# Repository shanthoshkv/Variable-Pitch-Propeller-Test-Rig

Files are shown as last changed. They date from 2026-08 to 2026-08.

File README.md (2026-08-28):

# Variable Pitch Propeller Test Rig

Design, CFD analysis, 3D-printed prototype, and experimental thrust testing of a manually adjustable variable-pitch propeller.

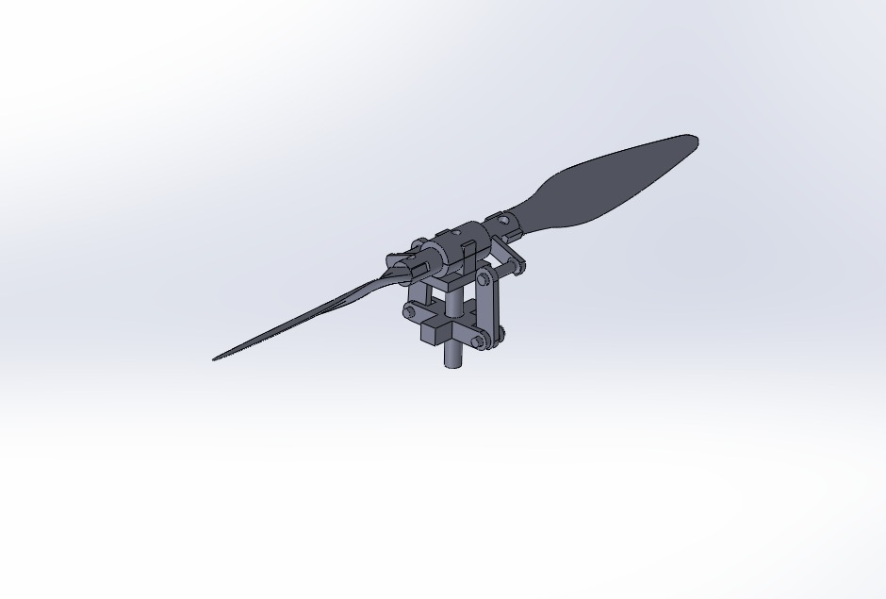
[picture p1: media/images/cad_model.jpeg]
CAD model of the variable-pitch propeller hub and blades


## Overview

Fixed-pitch propellers are only efficient at one operating point, the blade angle of attack that was optimal at the design condition goes off-optimal (or stalls) everywhere else. This project builds a variable-pitch propeller where blade pitch can be set mechanically via a rack-and-pinion hub, and tests how thrust changes with pitch angle from 0 to 30 degrees, using both CFD and a physical test bench, to see how closely a 3D-printed, non-actuated prototype tracks simulation.

Work was done as a group project (5 students, Aerospace Propulsion course, RVCE) covering the full pipeline: aerodynamic theory, CAD, CFD validation, fabrication, and instrumented testing.

## How it works

### Aerodynamic theory

The geometric pitch $P$ at blade radius $r$ relates to pitch angle $\beta$ by:

$$P = 2\pi r \tan(\beta)$$

and the propeller's operating condition is characterized by the advance ratio:

$$J = \frac{V}{nD}$$

where $V$ is advance velocity, $n$ is rotational speed (rev/s), and $D$ is diameter. Since this rig is a static-thrust bench (no forward airspeed), $J = 0$ for every test point, so the results characterize static thrust and stall onset vs. pitch, not the full thrust/efficiency curve across advance ratio.

Blade twist distribution was chosen so effective angle of attack stays reasonable across the pitch range rather than being optimized for one setting, following the approximation:

$$\theta(r) = \theta_{root} - \arctan\left(\frac{2(r - r_{hub})}{\pi r}\right)$$

where $\theta_{root}$ is root pitch angle and $r_{hub}$ is hub radius. This is the standard load-distribution twist used to keep the blade close to its aerodynamic optimum away from the hub region.

### Design and CFD

Blade geometry (twist distribution, chord, radius) was generated using Blade Element Momentum Theory (BEMT) via OpenProp, then parameterized in SolidWorks. Each of 16 pitch configurations (0 to 30 degrees) was simulated in SolidWorks Flow Simulation to get predicted thrust and to check for stall onset at low and high pitch extremes.

### Pitch mechanism

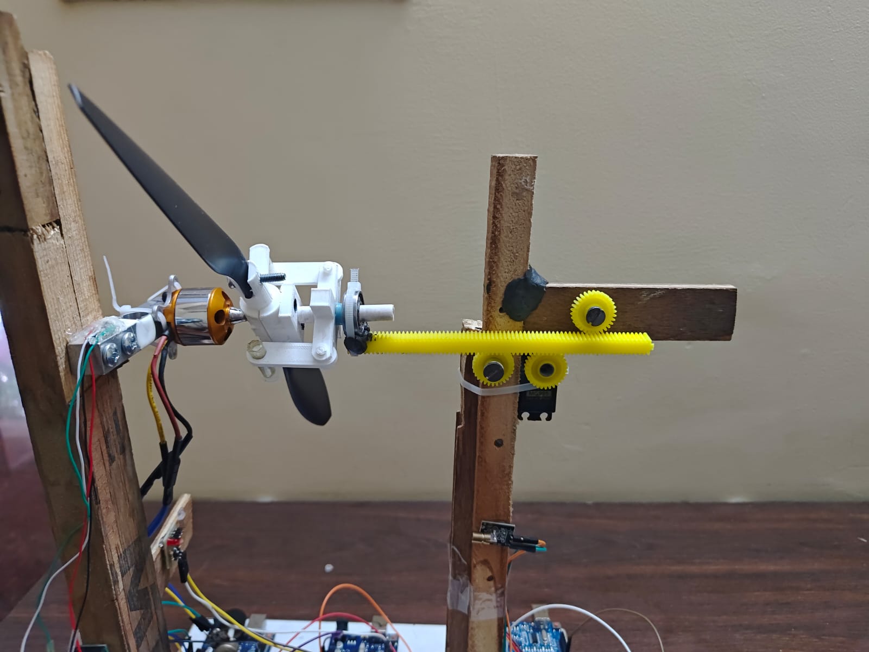
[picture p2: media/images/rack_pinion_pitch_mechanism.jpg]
Rack-and-pinion pitch mechanism, manually set and locked before each test run


A rack-and-pinion hub (`cad/hub.SLDPRT`, `cad/hub1.SLDPRT`, `cad/coupler.SLDPRT`) lets blade pitch be set manually and locked before a test run. It is not actuated in real time, there is no closed-loop pitch control here, this rig answers "how does thrust vary with pitch" rather than "can pitch be adjusted in flight."

### Fabrication

Blades and hub were 3D printed in PLA (`cad/print1 - CONT-1.STL`, `cad/print1 - string-1.STL`, and related STLs in `cad/`).

### Test bench

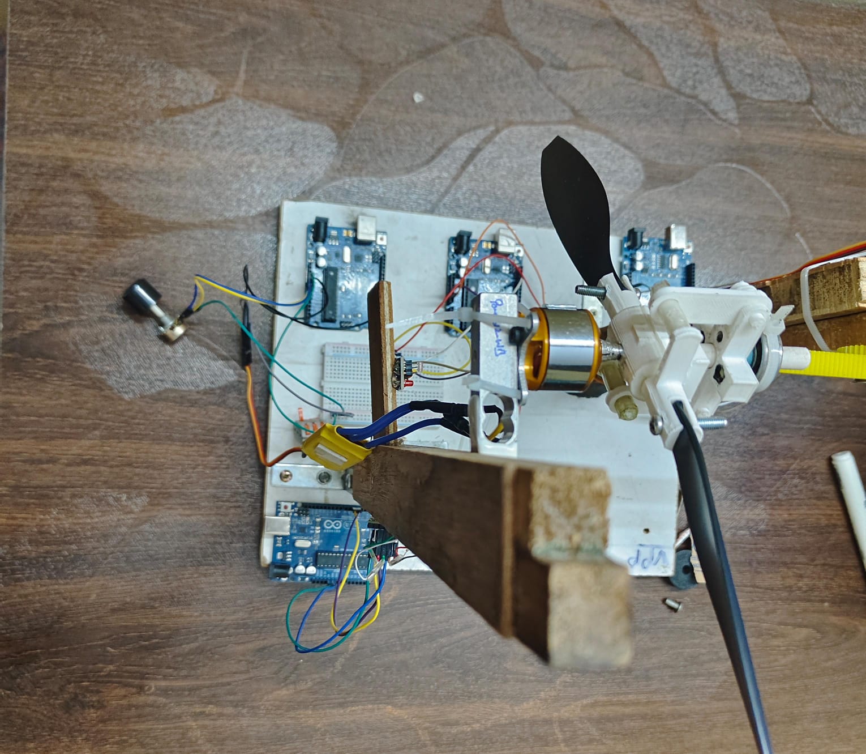
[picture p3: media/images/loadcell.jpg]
Test bench: brushless motor, load cell, and tachometer instrumentation


A brushless DC motor spins the prop. Three Arduino sketches handle instrumentation:

- `arduino-code/tachometer.ino` — RPM from an IR/optical blade-interrupt sensor, interrupt-driven with per-rotation smoothing.
- `arduino-code/loadcell.ino` / `loadcell_caliberation.ino` — thrust from an HX711 load cell amplifier, with a serial calibration routine (tare, known-mass calibration, EEPROM storage of the calibration factor) so the cell doesn't need re-calibrating on every boot.
- `arduino-code/rpm_control.ino` / `pitch_control_servo.ino` — motor speed and servo position set from a potentiometer for repeatable test-point setup.

For each pitch angle: lock the mechanism at that angle, spin up, and log RPM and thrust from the tachometer and load cell once readings settle.

## Results

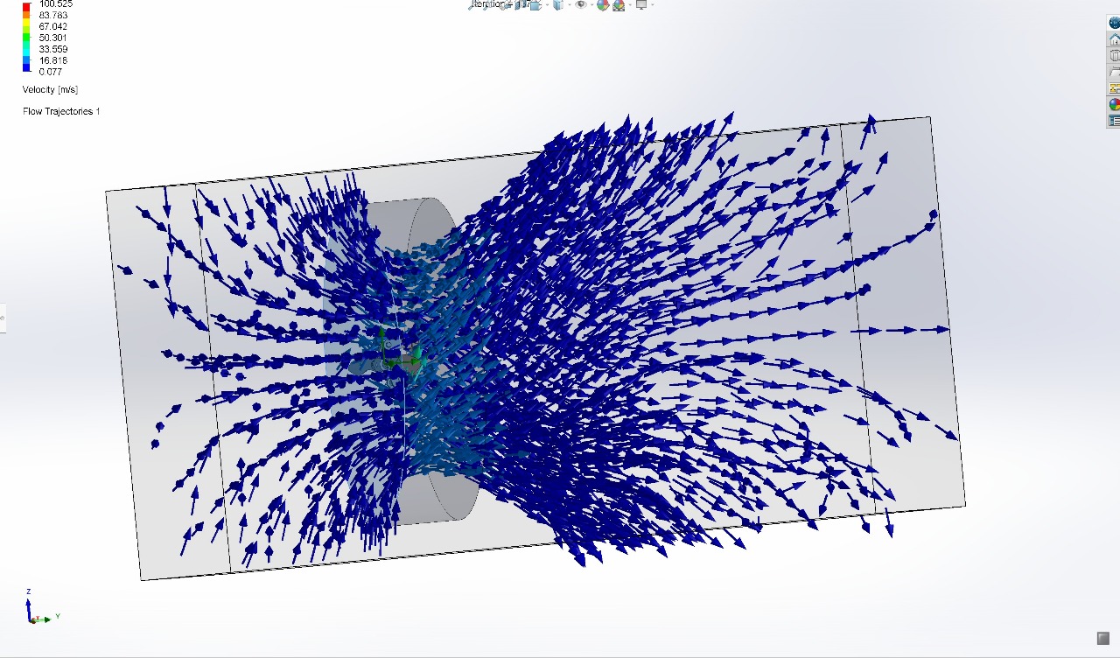
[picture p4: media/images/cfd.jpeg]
CFD flow simulation around the propeller at a test pitch angle


Max thrust of 3.00 N was observed at 28 degrees pitch, closely matching the CFD prediction. Thrust increases with pitch angle until aerodynamic stall effects start to reduce it near the top of the tested range. Experimental data tracked the simulated trend well across all 16 tested angles.

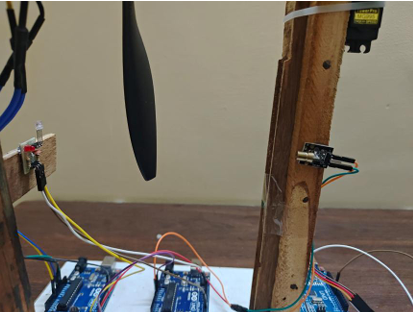
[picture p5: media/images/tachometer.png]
Tachometer readout during a test run


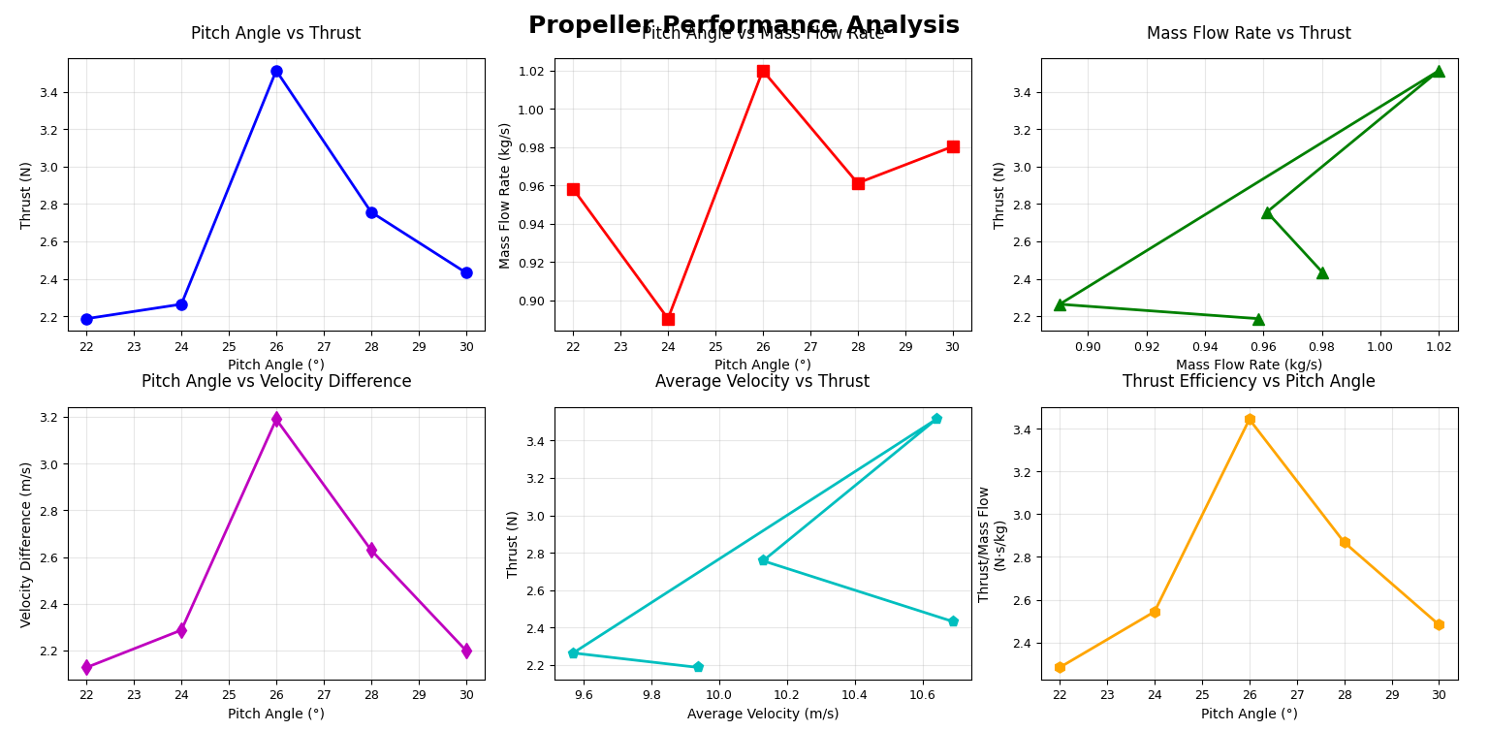
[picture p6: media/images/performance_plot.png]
Experimental and CFD thrust vs. pitch angle, showing the peak near 28 degrees


Video: `media/cad_pitch.mp4` (pitch mechanism CAD), `media/pitch_mechanism.mp4` (mechanism operation), `media/complete_working_model.mp4` (full test run).

Full writeup with methodology, CFD setup, theory background, and result plots: `docs/project_report.pdf`.

## Limitations

- Pitch is set manually between runs, not adjustable in flight or in real time, no closed-loop pitch actuator exists on this rig.
- Only 16 discrete pitch angles were tested, all at a single fixed RPM range from the bench motor, and all at $J = 0$ (static thrust only, no forward-flow/wind-tunnel testing).
- `media/images/python_output.png` implies a Python data-processing step was used to generate the result plots, but no Python script is checked into the repo, so the plotting step isn't reproducible from this repo alone.
- No structural/vibration analysis on the printed PLA blades at higher RPM, only the thrust and stall behavior were characterized.

## Repo layout

```
arduino-code/   RPM control, pitch servo control, tachometer, load cell + calibration
cad/            SolidWorks parts/assemblies and STLs for the hub, coupler, blades
docs/           full project report (PDF)
media/          photos, plots, and videos of the test rig and results
```

## Note

No matching page exists on the portfolio website for this project, this README is the primary documentation.

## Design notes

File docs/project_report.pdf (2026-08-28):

## RV COLLEGE OF ENGINEERING

## Design and Prototype Development of Variable Pitch Propeller

AEROSPACE PROPULSION

AS343AI

Under the Guidance of

Dr. Supreeth R

Associate Professor & Head Department of Aerospace Engineering

RV College of Engineering

In partial fulfilment for the award of degree of

Bachelor of Engineering

Aerospace Engineering

2024-2025

## RV COLLEGE OF ENGINEERING®, BENGALURU-59

Autonomous Institution Affiliated to VTU, Belagavi

## DEPARTMENT OF AEROSPACE ENGINEERING

CERTIFICATE

Certified that the Project Based Lab component of Aerospace Propulsion AS343AI course ti-

tled | is carried out by A

Uday Kiran (1RV23AS004), Rutuj Dugad Manoj (1RV23AS014), Tejas L (1RV23AS061),

Shanthosh K V (1RV23AS053), Yashwanth R (1RV23AS064) who are Bonafide students of

R.V. College of Engineering, Bengaluru, in partial fulfillment of the award of degree of Bach-

elor of Engineering in Aerospace Engineering of Visvesvaraya Technological University,

Belagavi during the year 2024-2025. It is certified that all corrections/suggestions indicated

for the Internal Assessment have been incorporated into the project-based laboratory report de-

posited in the departmental library. The report has been approved as it satisfies the academic

requirements in respect of Aerospace Propulsion Lab prescribed by the institution for the said

degree.

Signature of Internal Guide

External Viva

Name of Examiners | Signature with Date

1.

2.

I

RV COLLEGE OF ENGINEERING®
, BENGALURU-59

(Autonomous Institution Affiliated to VTU, Belag Vy, Belagavi)

DEPARTMENT OF AEROSPACE ENGINEERING

DECLARATION

We, A Uday Kiran (1RV23AS004), Rutuj Dugad Manoj (1RV23AS014), Tejas L (1RV23AS061),

Shanthosh K V (1RV23AS053), Yashwanth R (1RV23AS064), students of Fourth semester

B.E., Department of Aerospace Engineering, R.V. College of Engineering, Bengaluru, hereby

declare that the Project Based Lab of Aerospace Propulsion AS343AI course titled

has been carried out by us and

submitted in partial fulfilment for the award of degree of Bachelor of Engineering in Aerospace

Engineering during the year 2024-25.

Further, we declare that the content of the report has not been submitted previously by anybody

for the award of any degree or diploma to any other university.

We also declare that any Intellectual Property Rights generated out of this project carried out at

RVCE will be the property of the institute and we will be one of the authors of the same.

Place: Bengaluru

Date: 03/07/2025

Name | Signature

Akula Uday Kiran (1RV23AS004) Rutuj Dugad Manoj (1RV23AS014) Shanthosh K V (1RV23AS053) Tejas L (1RV23AS061) Yashwanth R (1RV23AS064)

II

## Acknowledgement

Our sincere thanks to Dr. Supreeth R, Associate Professor and Head, Department of Aerospace

Engineering, and the course coordinator for the Course Aerospace Propulsion AS343AI for his

support and encouragement.

We express our sincere gratitude to our beloved Principal, Dr. K. N. Subramanya for the

support for our Project Based Lab.

We thank all the teaching staff and technical staff of Aerospace Engineering department, RVCE, for

their help.

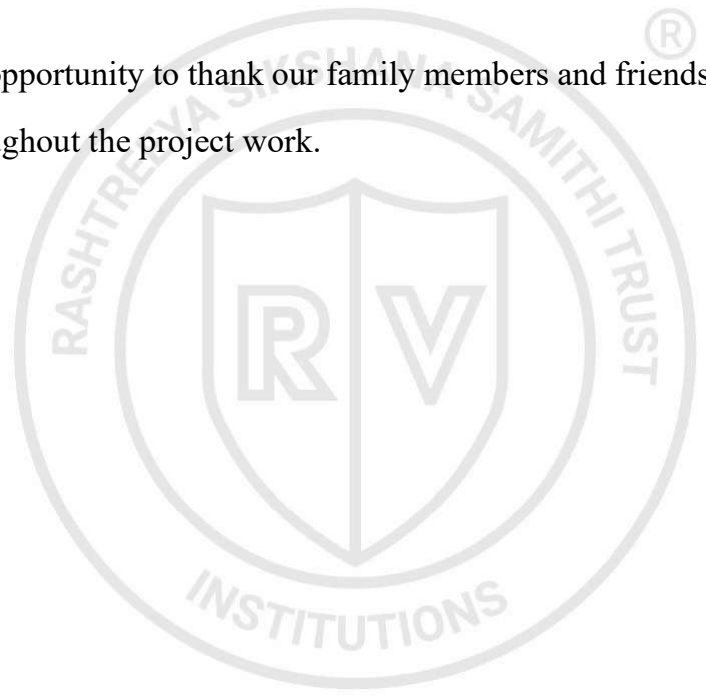
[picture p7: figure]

Lastly, we take this opportunity to thank our family members and friends who provided all the

backup support throughout the project work.

III

## Abstract

This project presents the design, simulation, fabrication, and experimental validation of a vari-

able pitch propeller system aimed at improving thrust generation across a range of operational

conditions. Unlike fixed-pitch systems, variable pitch propellers enable real-time adjustment

of blade pitch angles to optimize aerodynamic efficiency and propulsion performance. The

study begins with a detailed aerodynamic analysis using Blade Element and Momentum The-

ory, followed by parametric modeling in SolidWorks and simulation through CFD using Flow

Simulation tools. A total of 16 pitch configurations ranging from 0° to 30° were evaluated to

understand their influence on thrust.

The prototype was fabricated using 3D printing techniques in PLA material, and experimen-

tally tested using a brushless DC motor, load cell, and a tachometer-based thrust measurement

setup. Experimental data showed a strong correlation with simulation results, with the maxi-

mum thrust of 3.00 N observed at a pitch angle of 28°, closely matching simulated predictions.

The results confirmed that increased pitch angles lead to enhanced thrust until aerodynamic

stall effects appear. The study highlights the feasibility of manually tunable propeller blades

and lays the groundwork for future development of servo-actuated dynamic pitch systems for

UAVs and other aerospace platforms.

IV

# Contents

Certificate
Declaration
Acknowledgement
Abstract
1 Introduction | 1
2 CAD Modelling, CFD Analysis, Experimental model and Analysis | 5

V

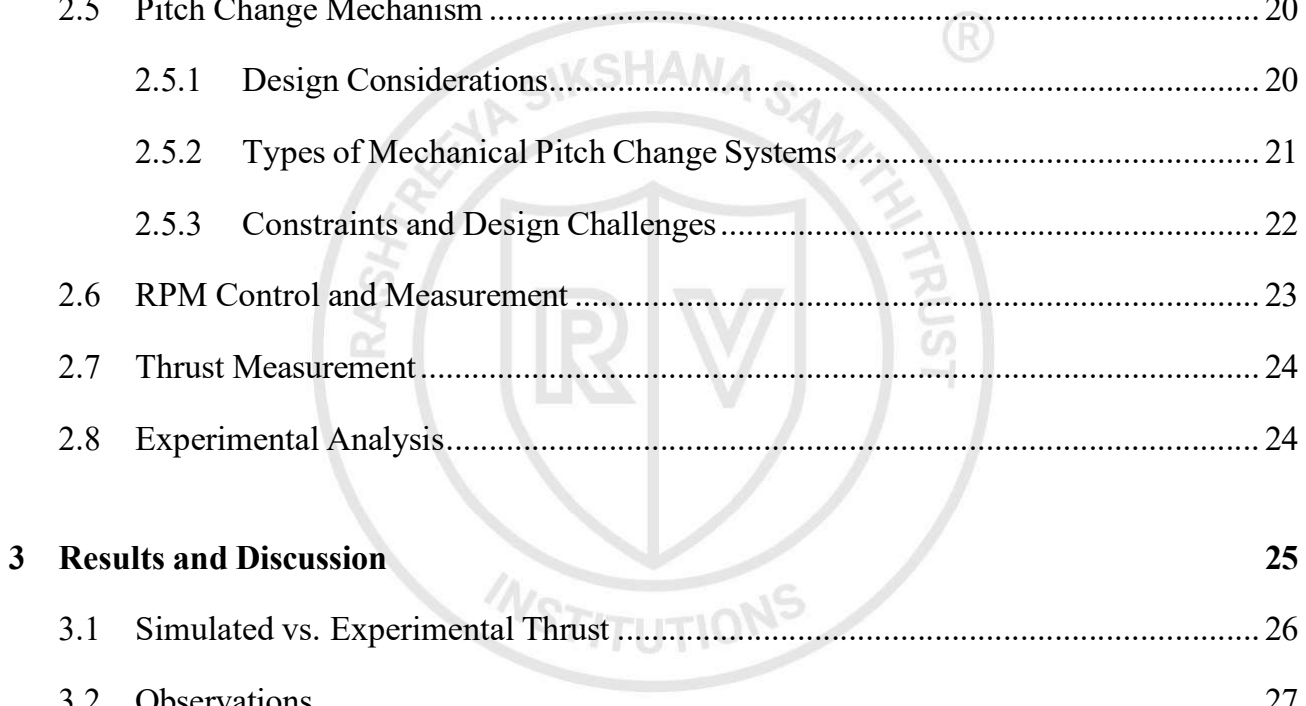
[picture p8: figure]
3 Results and Discussion

4 Conclusion and Future scope | 28

VII

# List of Figures

### 2.1 OpenProp Input Parameters | 17

### 2.2 Propeller Profiles | 17

### 2.3 Propeller Profiles in SolidWorks | 18

### 2.4 Bolt design and pitch controller | 18

### 2.5 Coupler design and hub design | 19

### 2.6 Final Assembly | 19

### 2.7 Flow simulation of propeller at a pitch angle of 20 degrees | 20

### 2.8 Goal plots extracted from simulation of propeller at a pitch angle of 20 degrees 20

### 2.9 Velocity contour of the propeller at a pitch angle of 20 degrees | 20

### 2.10 Flow simulation shows stalling at 2 degrees | 21

### 2.11 Flow simulation shows stalling at 30 degrees | 21

### 2.12 Pitch change mechanism | 29

### 2.13 Tachometer | 30

### 2.14 RPM Control and Thrust Measurement | 30

VIII

Variable Pitch Propeller

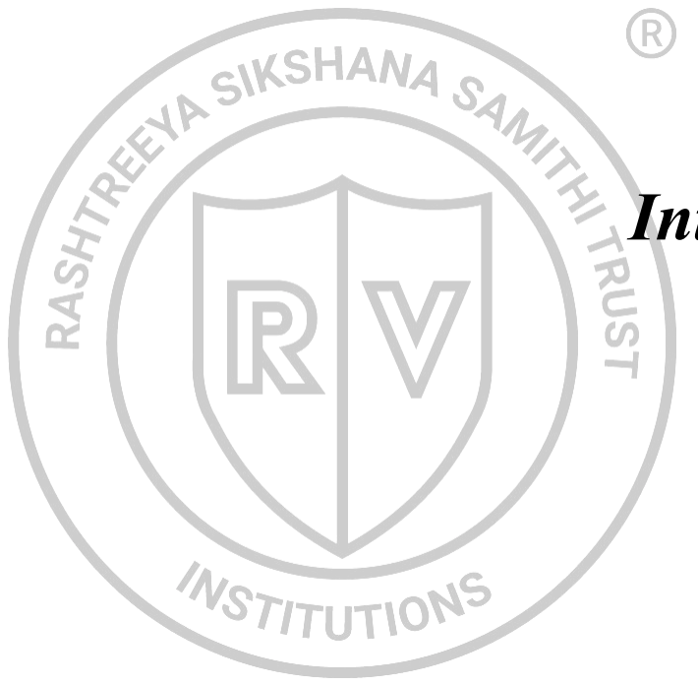
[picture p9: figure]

Department of Aerospace Engineering | 2024-2025 | Page 1

# Chapter 1 Introduction

Variable pitch propellers represent one of the most significant technological advancements in

propulsion systems, fundamentally transforming how aircraft and marine vessels optimize their

performance across varying operational conditions. Unlike fixed-pitch propellers that maintain

constant blade angles, variable pitch propellers enable real-time adjustment of blade pitch an-

gles, allowing for optimal thrust generation and efficiency across different flight phases or

operating speeds.

The concept of variable pitch propulsion emerged from the inherent limitations of fixed-pitch

systems, which can only achieve optimal efficiency at a single design point. In aviation, air-

craft experience dramatically different operating conditions during takeoff, climb, cruise, and

landing phases, each requiring different thrust and efficiency characteristics. Similarly, marine

vessels encounter varying sea conditions, speeds, and loading scenarios that benefit from pitch

adjustment capabilities.

The development of variable pitch propeller technology has been driven by the continuous pur-

suit of improved fuel efficiency, enhanced performance, and operational flexibility. Modern

variable pitch systems incorporate sophisticated control mechanisms, advanced materials, and

precise manufacturing techniques to achieve remarkable levels of performance optimization.

These systems have become standard equipment in commercial aviation, military aircraft, and

high-performance marine applications.

This report provides a comprehensive examination of variable pitch propeller technology, ex-

ploring the theoretical foundations, design principles, control systems, and practical applica-

tions that define modern propulsion systems. The analysis encompasses both aerospace and

marine applications, highlighting the unique challenges and solutions associated with each do-

main.

### 1.1 Propeller Aerodynamics and Hydrodynamics

The operation of variable pitch propellers is governed by fundamental principles of fluid dy-

namics, whether operating in air for aircraft or water for marine vessels. Understanding these

principles is essential for comprehending how pitch variation affects propeller performance and

overall system efficiency.

### 1.1.1 Pitch Angle Effects

The pitch angle β fundamentally determines the propeller‘s thrust and torque characteristics.

Increasing pitch angle generally increases the theoretical advance per revolution but also in-

creases the angle of attack, potentially leading to stall conditions. The relationship between

pitch angle and performance is complex and depends on operating conditions.

The geometric pitch P at radius r is related to the pitch angle by:

P = 2πr tan(β) | (1.1)

The advance ratio J is a dimensionless parameter that characterizes the propeller‘s operating

condition:

(1.2)

where V is the advance velocity.

Variable pitch propellers employ various mechanical systems to adjust blade pitch angles during

operation. The choice of mechanism depends on application requirements, including response

time, precision, reliability, and power consumption.

### 1.2.1 Hydraulic Systems

Hydraulic pitch control systems are widely used in aviation applications due to their high

power-to-weight ratio and rapid response capabilities. These systems typically employ engine

oil or dedicated hydraulic fluid to actuate pitch change mechanisms.

The basic hydraulic system consists of a governor unit that senses propeller speed and controls

oil flow to a pitch change mechanism within the propeller hub. The pitch change mechanism

converts hydraulic pressure into mechanical motion that rotates the propeller blades about their

longitudinal axes.

### 1.2.2 Electric Systems

Electric pitch control systems offer precise control and are increasingly used in modern appli-

cations. These systems employ electric motors, typically stepper motors or servo motors, to

drive pitch change mechanisms through gear reduction systems.

The torque requirements for electric pitch control systems must overcome both aerodynamic

moments and system friction:

Tmotor = Taero + Tfriction + Jsystemαangular | (1.3)

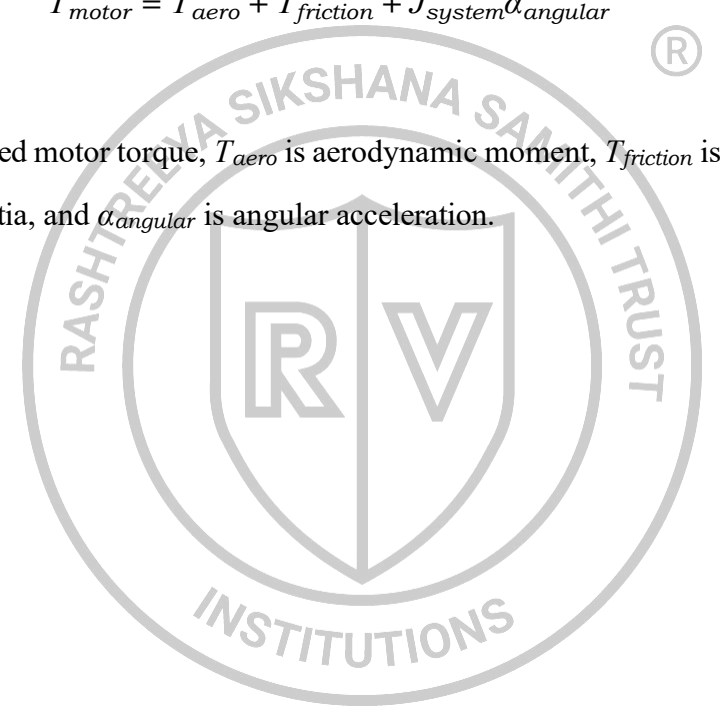
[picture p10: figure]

where Tmotor is required motor torque, Taero is aerodynamic moment, Tfriction is friction torque,

Jsystem is system inertia, and αangular is angular acceleration.

# Chapter 2

π
r

### 2.1 Blade Design and Geometry

The design of variable pitch propeller blades requires careful consideration of aerodynamic ef-

ficiency, structural integrity, and manufacturing constraints. Unlike fixed-pitch blades, variable

pitch blades must maintain acceptable performance across a wide range of pitch angles.

### 2.1.1 Twist Distribution

Blade twist distribution must be optimized for variable pitch operation, considering that the

effective twist changes as pitch angle varies. The total twist at any radial station is the sum of

built-in geometric twist and pitch angle adjustment.

The optimal twist distribution for maximum efficiency can be approximated by:

β(r) = β −

2
arctan

(
rhub

)
(2.1)

where βroot is root pitch angle and rhub is hub radius.

### 2.1.2 Geometric Parameters

Number of Blades: The number of propeller blades affects thrust distribution, vibration char-

acteristics, and manufacturing complexity. Fewer blades generally provide higher efficiency but

may result in increased vibration and noise. More blades offer smoother operation and better

thrust distribution but at the cost of increased complexity and potential efficiency penalties.

Rotor Diameter: The propeller diameter is one of the most critical design parameters, directly

affecting the propeller‘s thrust-producing capability and efficiency. Larger diameters generally

provide better efficiency due to lower disk loading, but are constrained by ground clearance,

structural considerations, and installation requirements.

Hub Diameter: The hub diameter defines the central portion of the propeller and affects the

blade root design, structural attachment, and flow characteristics near the hub. The hub-to-tip

ratio influences the effective working area of the propeller and affects both performance and

root

structural design.

### 2.1.3 Operating Conditions

Rotation Speed (RPM): The propeller rotational speed determines the blade tip speed and af-

fects both aerodynamic performance and structural loads. Higher rotational speeds can provide

more thrust from a given diameter but may encounter compressibility effects and increased

noise at high tip speeds.

Ship Speed (Forward Velocity): This parameter defines the advance velocity of the propeller

through the fluid medium. It is crucial for determining the advance ratio, which characterizes

the propeller‘s operating condition and affects the angle of attack distribution along the blade.

Required Thrust: The design thrust requirement determines the propeller‘s loading and influ-

ences blade geometry optimization. This parameter is typically derived from the vehicle‘s drag

characteristics and performance requirements.

Fluid Density: The density of the operating medium (air or water) affects thrust production,

power requirements, and Reynolds number. This parameter varies with altitude, temperature,

and atmospheric conditions for aircraft, or with water temperature and salinity for marine ap-

plications.

### 2.1.4 Computational Grid Parameters

Radial Panels: This parameter defines the number of computational divisions along the blade

span from hub to tip. More radial panels provide higher resolution in the spanwise direction,

allowing for more accurate representation of blade geometry and flow characteristics. However,

increased panel count also increases computational time and complexity.

Chordwise Panels: This parameter specifies the number of computational divisions along the

blade chord from leading edge to trailing edge. Higher chordwise panel counts improve the

accuracy of pressure distribution calculations and airfoil representation, particularly important

for capturing leading edge and trailing edge effects.

### 2.1.5 Blade Geometry Parameters

r/R (Radial Position): This dimensionless parameter represents the radial position along the

blade span, where r is the local radius and R is the propeller tip radius. Values range from the

hub ratio (typically 0.15-0.25) to 1.0 at the tip. This parameter defines the stations where blade

properties are specified.

c/D (Chord-to-Diameter Ratio): This parameter defines the local blade chord length as a

fraction of the propeller diameter. The chord distribution affects blade loading, structural char-

acteristics, and manufacturing requirements. Optimal chord distributions balance aerodynamic

efficiency with structural and manufacturing constraints.

Cd (Drag Coefficient): The local drag coefficient represents the airfoil section ‘s drag charac-

teristics at each radial station. This parameter is typically derived from airfoil data and affects

the propeller ‘s power requirements and efficiency calculations.

t0/D (Thickness-to-Diameter Ratio): This parameter defines the maximum blade thickness at

each radial station as a fraction of the propeller diameter. Blade thickness distribution affects

structural strength, manufacturing requirements, and aerodynamic performance.

Skew: Blade skew refers to the circumferential offset of blade sections at different radial po-

sitions. Skew is used to reduce noise, vibration, and cavitation by distributing blade loading

more evenly in time. Forward skew moves outer blade sections ahead of inner sections in the

direction of rotation.

Xs/D (Skew Distribution): This parameter quantifies the skew distribution along the blade

span. The skew distribution affects the propeller ‘s acoustic signature, vibration characteristics,

and hydrodynamic performance.

### 2.1.6 Parametric Design using OpenProp

The design process begins with processing input parameters:

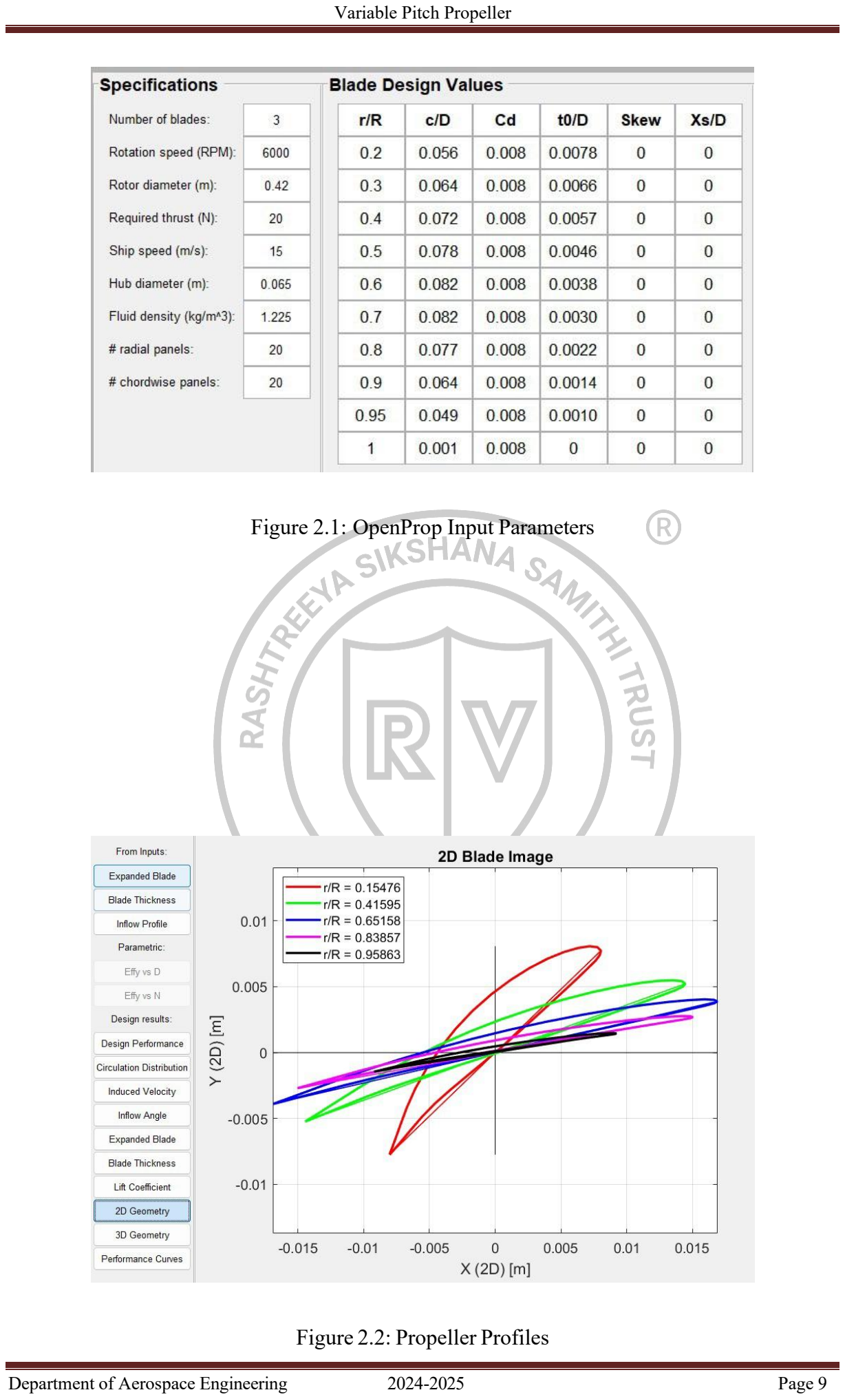
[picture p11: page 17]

Figure 2.1: OpenProp Input Parameters

Figure 2.2: Propeller Profiles

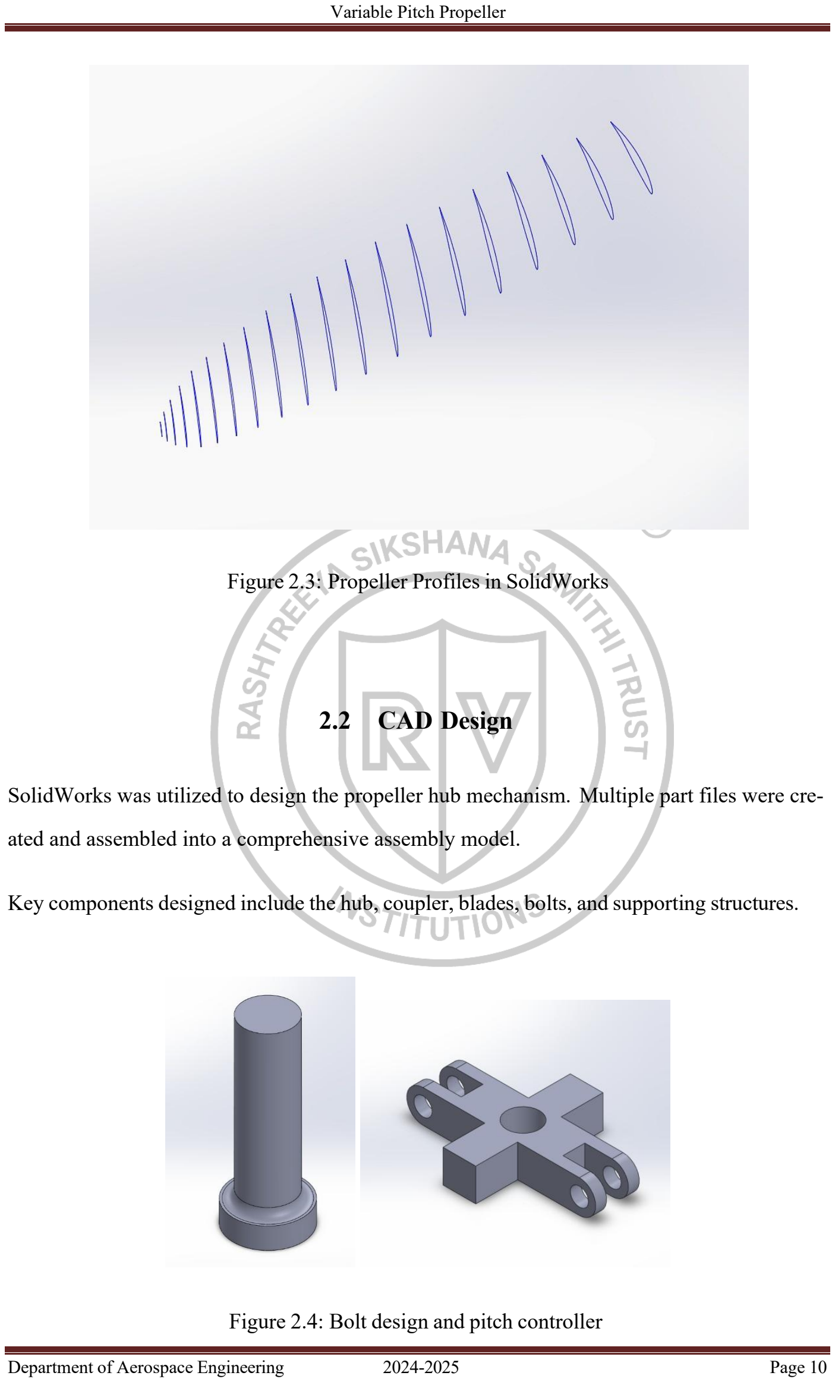
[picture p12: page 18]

Figure 2.3: Propeller Profiles in SolidWorks

### 2.2 CAD Design

SolidWorks was utilized to design the propeller hub mechanism. Multiple part files were cre-

ated and assembled into a comprehensive assembly model.

Key components designed include the hub, coupler, blades, bolts, and supporting structures.

Figure 2.4: Bolt design and pitch controller

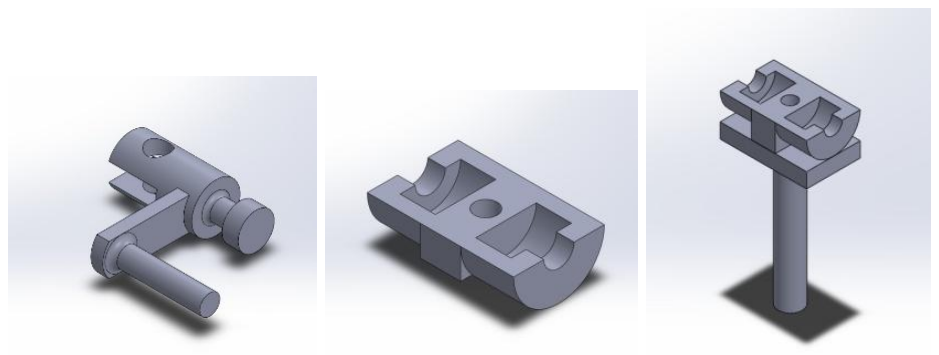
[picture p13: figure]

Figure 2.5: Coupler design and hub design

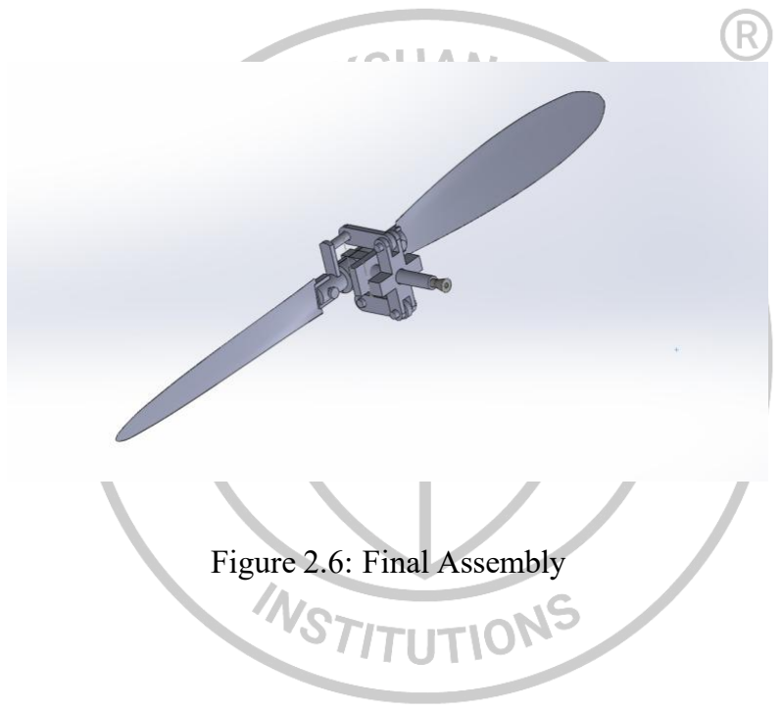
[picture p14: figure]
Figure 2.6: Final Assembly

### 2.3 CFD Simulations

For computational fluid dynamics (CFD) analysis, SolidWorks Flow Simulation was employed.

Appropriate boundary conditions were defined, including an environmental pressure setup. All

simulations were performed at an operating speed of 3000 RPM to evaluate aerodynamic per-

formance.

Below are the related simulation and model images:

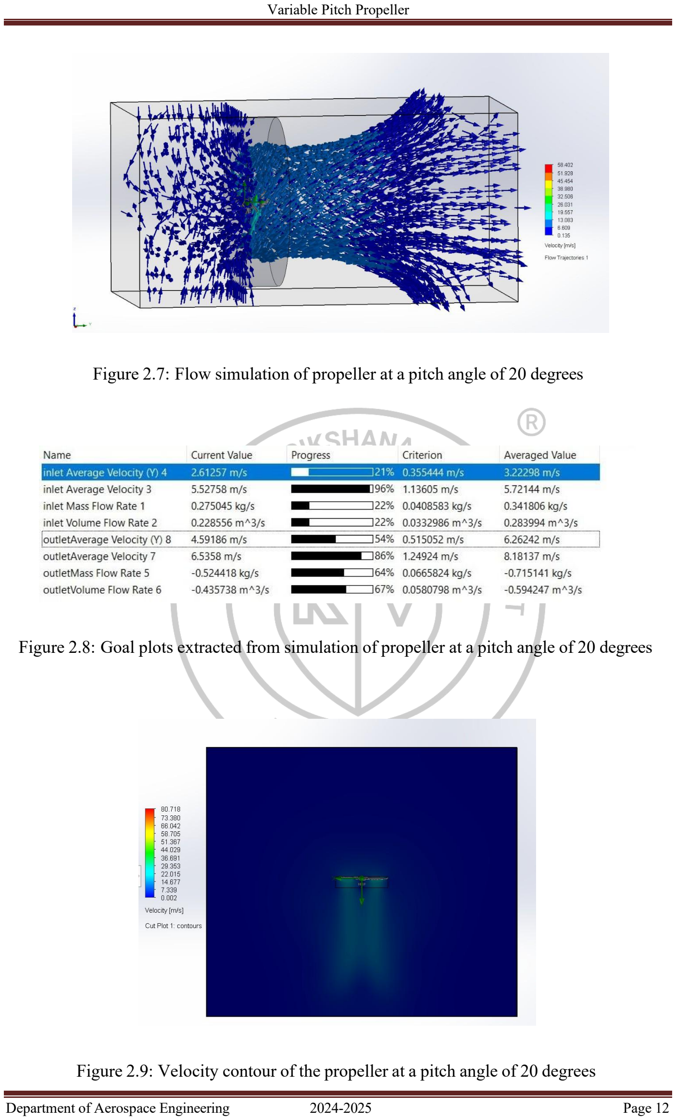
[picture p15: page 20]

Figure 2.7: Flow simulation of propeller at a pitch angle of 20 degrees

Figure 2.8: Goal plots extracted from simulation of propeller at a pitch angle of 20 degrees

Figure 2.9: Velocity contour of the propeller at a pitch angle of 20 degrees

### 2.3.1 Stall Analysis

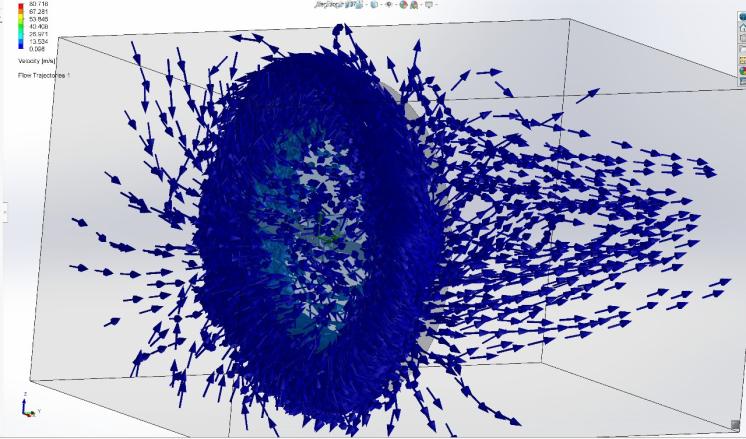
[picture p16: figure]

Figure 2.10: Flow simulation shows stalling at 2 degrees.

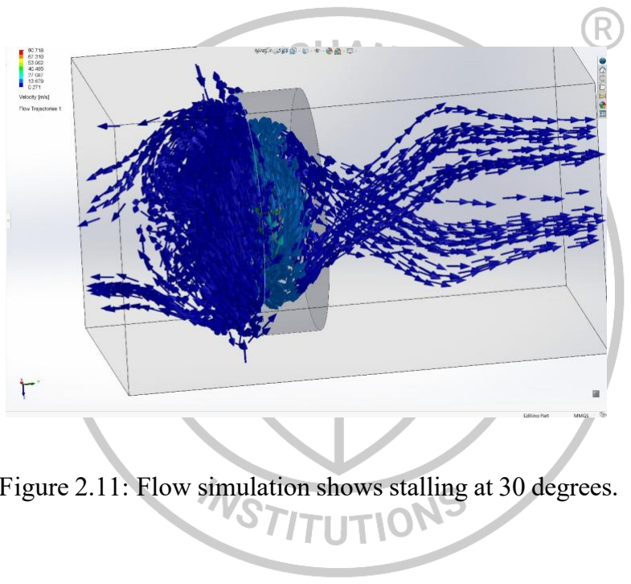
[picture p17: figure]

Figure 2.11: Flow simulation shows stalling at 30 degrees.

### 2.4 Methodology

The following methodology outlines the comprehensive steps taken to design, simulate, fabri-

cate, and test a variable pitch propeller system. This includes both computational simulations

in SolidWorks and CFD tools, as well as physical prototyping using 3D printing and real-world

thrust testing.

### 2.4.1 Project Workflow Overview

The methodology is divided into the following key stages:

- Conceptual Design and Pitch Mechanism Study
- CAD Modelling of Blades and Hub in SolidWorks
- Pitch Angle Variations and Configuration Generation
- CFD Simulation in Flow Simulation Module
- Physical Fabrication Using 3D Printing
- Experimental Setup Development
- Thrust Measurement and Data Collection

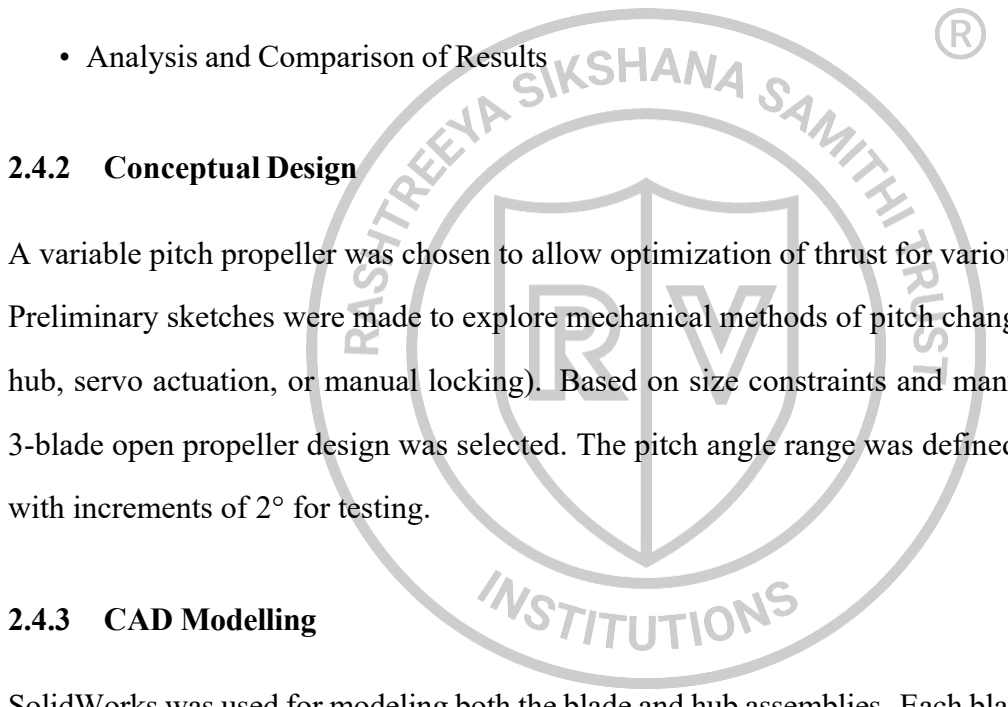
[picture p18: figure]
• Analysis and Comparison of Results; 2.4.2 Conceptual Design; with increments of 2° for testing.; 2.4.3 CAD Modelling

A variable pitch propeller was chosen to allow optimization of thrust for various flight phases.

Preliminary sketches were made to explore mechanical methods of pitch change (e.g., rotating

hub, servo actuation, or manual locking). Based on size constraints and manufacturability, a

3-blade open propeller design was selected. The pitch angle range was defined from 0° to 30°

SolidWorks was used for modeling both the blade and hub assemblies. Each blade was designed

with a root rotation feature, allowing pitch variation. Blades were parametrically modelled to

allow quick pitch adjustments using the design table. 16 configurations were generated for

pitch angles from 0° to 30° (0°, 2°, 4°, ..., 30°). The hub was designed with radial sockets to

hold the blade roots securely while allowing rotation.

### 2.4.4 CFD Simulation of Each Pitch Angle

The Flow Simulation module in SolidWorks was used to simulate airflow across the propeller

blades at each pitch. Boundary Conditions:

- Inlet velocity calculated based on rotational speed (3000 RPM).
- Environmental air, standard sea-level conditions.
- Rotation region was used to simulate the propeller motion.

Simulations were run for each pitch angle to extract:

- Thrust force
- Drag force
- Lift-to-drag ratio

Post-processing involved comparing force output vs pitch angle and identifying optimal per-

formance range.

### 2.4.5 Fabrication

3D printing (FDM type, PLA material) was used for blade and hub production. Each blade was

printed with locking holes for setting pitch manually using alignment pins. The hub was printed

as a modular design to enable easy insertion and removal of blades. Blades were sanded,

balanced, and checked for alignment before mounting.

### 2.4.6 Test Bench and Experimental Setup

The physical setup involved:

- DC brushless motor (3000 RPM rated) as the propulsion source.
- Laser tachometer to measure actual RPM.
- Load cell-based thrust measurement system mounted behind the propeller.
- A digital pitch protractor to verify pitch angle before testing.
- Control system to adjust RPM via ESC and throttle input.

### 2.4.7 Experimental Procedure

- Blade pitch was set manually using alignment pins at predefined angles.
- Motor RPM was increased incrementally using a throttle controller.
- For each pitch angle, thrust data was recorded at 3000 RPM.
- Five trials were taken for each configuration to average out fluctuations.
- The final measured thrust values were compared against simulation results.

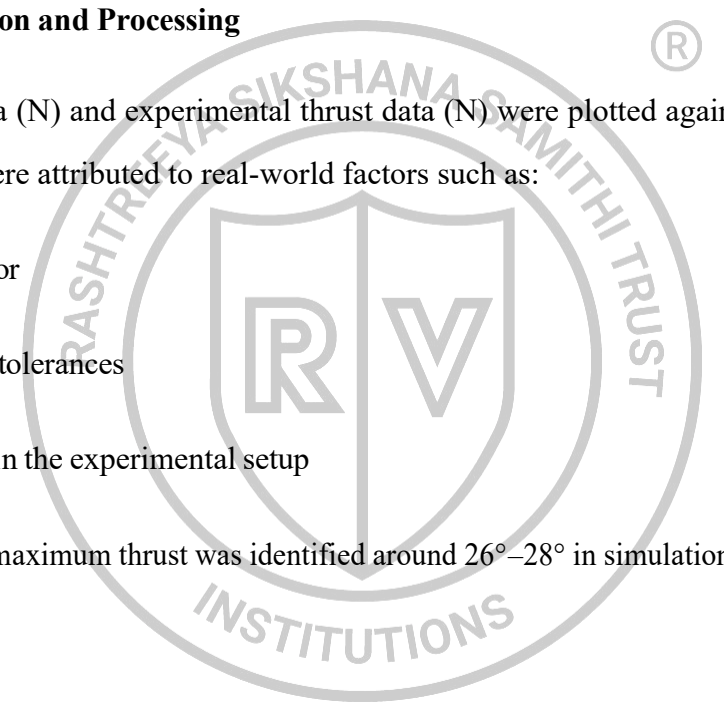
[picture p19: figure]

### 2.4.8 Data Collection and Processing

Simulation thrust data (N) and experimental thrust data (N) were plotted against pitch angles.

Any discrepancies were attributed to real-world factors such as:

- Tachometer error
- Manufacturing tolerances
- Airflow losses in the experimental setup

The optimal pitch for maximum thrust was identified around 26°–28° in simulation and 24°–26° in

physical tests.

### 2.4.9 RPM Control System

To rotate the propeller at the required speed for testing, a brushless DC (BLDC) motor was

used. It was controlled using an Electronic Speed Controller (ESC) interfaced with a throttle

system.

- Motor: A high-torque BLDC motor rated for continuous operation at 3000 RPM.
- ESC: An electronic controller capable of translating PWM (pulse-width modulation)

signals from the throttle to the motor.

- Power Source: A stable 12V–14.8V DC power supply or LiPo battery.
- Throttle Input: Manual potentiometer-based throttle to precisely vary the motor speed.

The ESC allowed for smooth acceleration and fine RPM adjustment to match the simulation

condition of 3000 RPM.

This section outlines the experimental procedures, instruments, and findings associated with

measuring thrust and controlling propeller performance in the physical prototype. It comple-

ments the simulation studies by validating them through practical data.

### 2.4.10 RPM Control and Measurement

RPM Control System

To rotate the propeller at the required speed for testing, a brushless DC (BLDC) motor was

used. It was controlled using an Electronic Speed Controller (ESC) interfaced with a throttle

system.

- Motor: A high-torque BLDC motor rated for continuous operation at 3000 RPM.
- ESC: An electronic controller capable of translating PWM (pulse-width modulation)

signals from the throttle to the motor.

- Power Source: A stable 12V–14.8V DC power supply or LiPo battery.
- Throttle Input: Manual potentiometer-based throttle to precisely vary the motor speed.

The ESC allowed for smooth acceleration and fine RPM adjustment to match the simulation

condition of 3000 RPM.

RPM Measurement

To accurately measure the RPM of the rotating propeller, a non-contact laser tachometer was

used. Working Principle: A small piece of reflective tape was applied to the hub of the ro-

tating propeller. The tachometer emitted a laser beam and detected the tape’s reflection during each revolution. Device Used: Handheld digital laser tachometer (±10 RPM accuracy). Lim-

itations: While effective, there is potential for measurement delay or under-reading at high

speeds due to light interference or misalignment. Note: In testing, the tachometer sometimes

read ∼2800–2950 RPM, though the motor was calibrated for 3000 RPM. This small discrep-

ancy may explain why experimental thrust exceeded simulation predictions.

### 2.4.11 Thrust Measurement

Purpose

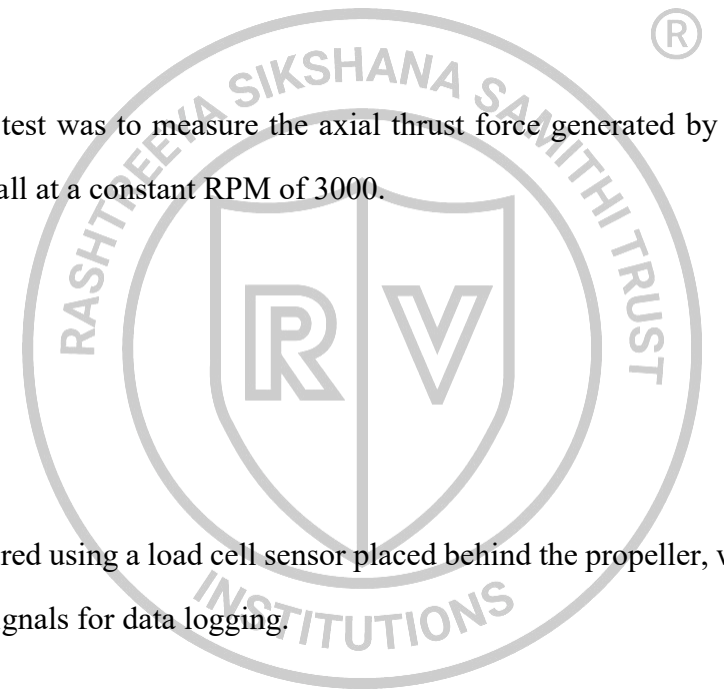
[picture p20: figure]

The core goal of the test was to measure the axial thrust force generated by the propeller at

various pitch angles, all at a constant RPM of 3000.

Setup Description

The thrust was measured using a load cell sensor placed behind the propeller, which converted

force into electrical signals for data logging.

Table 2.1: Equipment Used in Thrust Measurement

Component | Description
Load Cell HX711 Amplifier Arduino UNO Test Stand Propeller Mount | 5 kg strain gauge, linear output Signal amplifier and ADC module for load cell Microcontroller for data logging Rigid frame to isolate vibration and torque Center-aligned shaft for consistent rotation

### 2.4.12 Experimental Results and Analysis

Summary of Results

Table 2.2: Simulated vs Experimental Thrust

Pitch Angle (°) | Avg Simulated Thrust (N) | Avg Experimental Thrust (N)
0 2 4 . 24 26 28 30 | 0.12 0.26 0.39 . 2.10 2.18 2.20 2.19 | 0.16 0.29 0.41 . 2.81 2.90 3.00 2.97

Observations

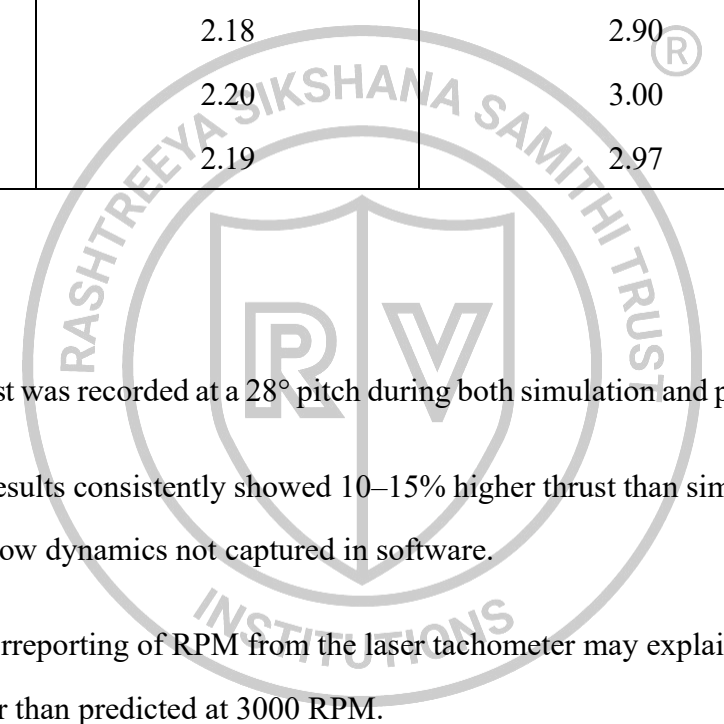
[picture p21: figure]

- Maximum thrust was recorded at a 28° pitch during both simulation and physical testing.
- Experimental results consistently showed 10–15% higher thrust than simulations, likely

due to real airflow dynamics not captured in software.

- The slight underreporting of RPM from the laser tachometer may explain why thrust

appeared higher than predicted at 3000 RPM.

Sources of Error

Table 2.3: Identified Sources of Error

Source | Explanation
Tachometer Delay/Error Airflow Recirculation Load Cell Drift 3D Print Tolerances | RPM may be lower than actual, leading to thrust mismatch. Indoor testing caused unsteady flow near the wall. Minor thermal or electrical drift during operation. Surface roughness may increase lift in some conditions.

Improvements for Future Testing

- Use a high-speed camera with motion tracking for RPM validation.
- Mount propeller in an open wind tunnel to minimize airflow recirculation.
- Introduce automated pitch control using servos for dynamic pitch testing.

### 2.4.13 Improvements for Future Testing

- Use a high-speed camera with motion tracking for RPM validation.

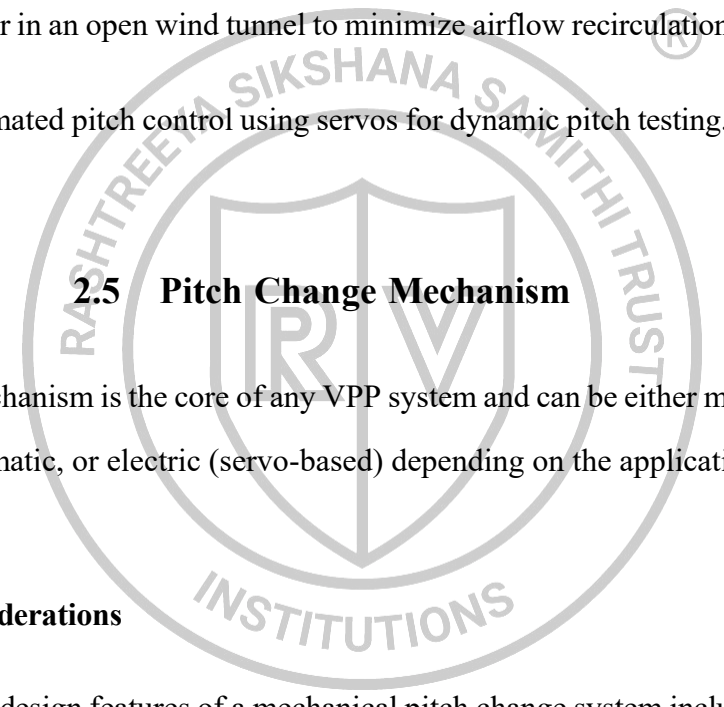
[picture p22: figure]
2.5 Pitch Change Mechanism

- Mount propeller in an open wind tunnel to minimize airflow recirculation.
- Introduce automated pitch control using servos for dynamic pitch testing.

The pitch change mechanism is the core of any VPP system and can be either manual, mechan-

ical, hydraulic, pneumatic, or electric (servo-based) depending on the application scale.

### 2.5.1 Design Considerations

Key components and design features of a mechanical pitch change system include:

a. Blade Root Bearings

Each blade is mounted in the hub using a bearing arrangement that permits it to rotate smoothly

about its axis. Common bearing types include:

- Radial ball bearings
- Thrust bearings for axial loads b. Rotating Sleeve / Hub Socket

The hub houses a rotating sleeve or cam mechanism that either directly rotates the blade roots

or transmits rotation from an actuation source (like a servo arm).

c. Pushrod or Rack Mechanism

A pushrod or gear rack system can be used to transmit axial motion to the rotating part of the

blade. For example:

- A conical cam pushes against a slot in the blade root

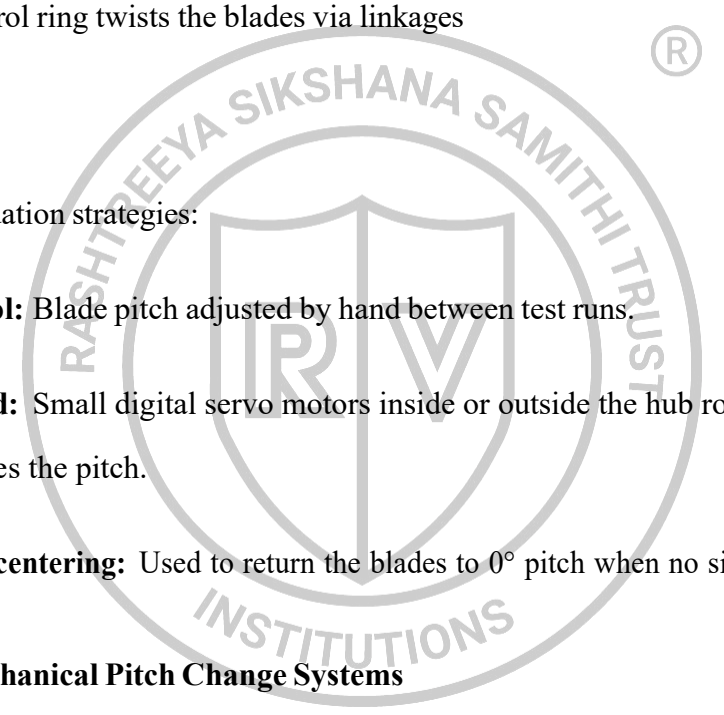
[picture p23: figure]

- A rotating control ring twists the blades via linkages
d. Actuation System

There are several actuation strategies:

- Manual control: Blade pitch adjusted by hand between test runs.
- Servo-actuated: Small digital servo motors inside or outside the hub rotate a control

ring that changes the pitch.

- Spring-loaded centering: Used to return the blades to 0° pitch when no signal is applied.

### 2.5.2 Types of Mechanical Pitch Change Systems

Rotating Collar Type (Common in RC Aircraft)

- A collar slides axially and twists each blade via linkages.
- Actuated by a servo that pulls/pushes the collar.
- Reliable and suitable forsmall UAV applications.

Rack-and-Pinion Mechanism

- Each blade has a pinion gear at its root.

- A central rack slides axially and rotates each blade proportionally.
- Good synchronization but more complex.

Swashplate Mechanism (Helicopter-style, Advanced)

- Transmits motion via a tilting plate that changes blade pitch cyclically or collectively.
- Complex and used in quadcopters or helicopters.

### 2.5.3 Constraints and Design Challenges

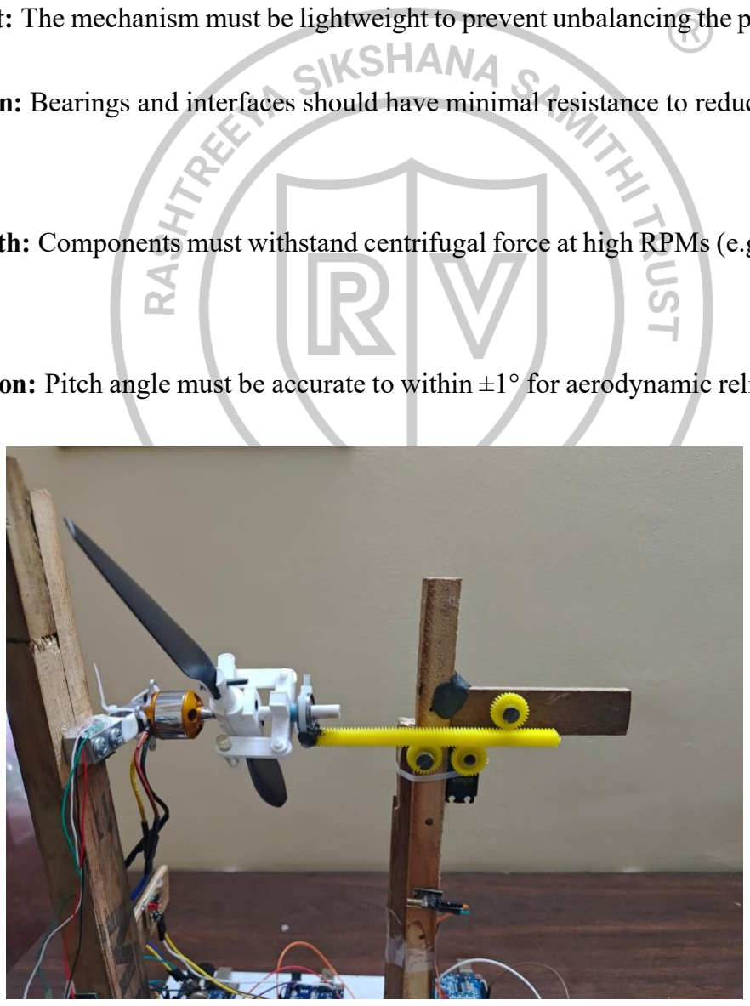
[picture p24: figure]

- Weight: The mechanism must be lightweight to prevent unbalancing the propeller.
- Friction: Bearings and interfaces should have minimal resistance to reduce load on ac-

tuators.

- Strength: Components must withstand centrifugal force at high RPMs (e.g., 3000–5000

RPM).

- Precision: Pitch angle must be accurate to within ±1° for aerodynamic reliability.

Figure 2.12: Pitch change mechanism

### 2.6 RPM Control and Measurement

To control the speed of the propeller, we have attached an ESC to the BLDC motor, which is

controlled by an arduino and we can change the speed of the motor by using a potentiometer.

A Laser Tachometer has be installed, which measures the speed of the propeller in real time

and displays it.

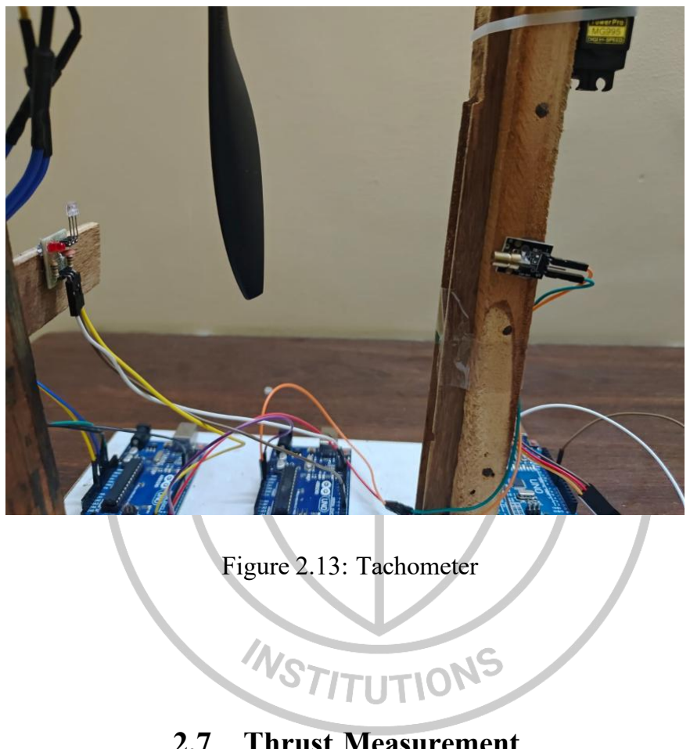
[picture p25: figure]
Figure 2.13: Tachometer

### 2.7 Thrust Measurement

To measure the thrust of the propeller, we have used a Load Cell. The load cell is placed on a

vertical stand, attached to it is the propeller

### 2.8 Experimental Analysis

Upon running the prototype at 3000 RPM and at different pitch angles, these are the values

obtained.

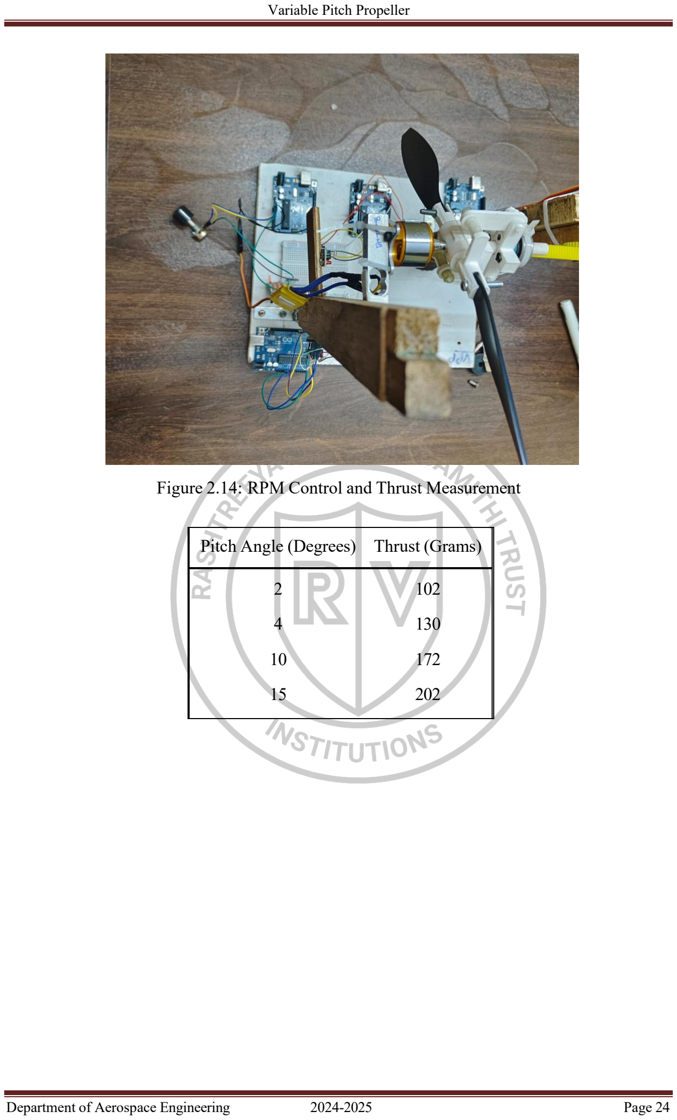
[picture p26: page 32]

Figure 2.14: RPM Control and Thrust Measurement

Pitch Angle (Degrees) Thrust (Grams)

2 | 102
4 | 130
10 | 172
15 | 202

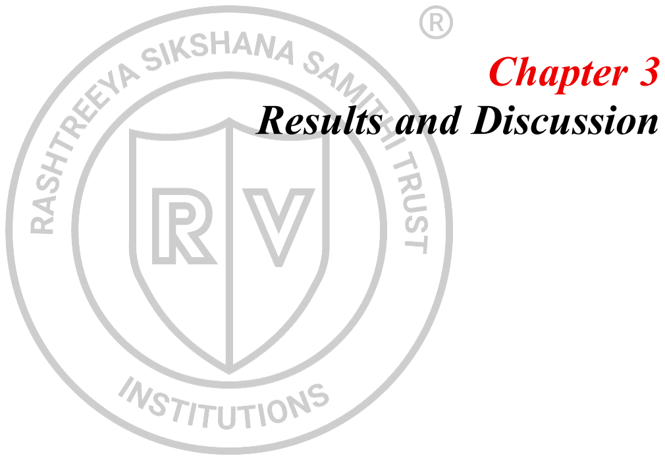
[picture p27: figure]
Results and Discussion

# Chapter 3

### 3.1 Simulated vs. Experimental Thrust

Table 3.1: Simulated vs. Experimental Thrust

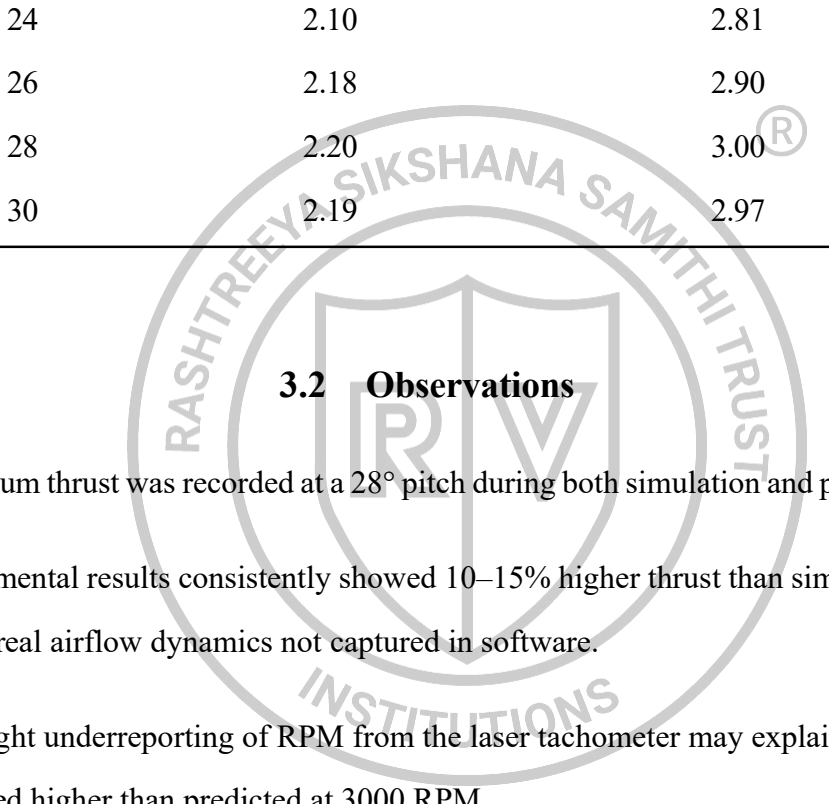
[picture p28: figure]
3.2 Observations

- Maximum thrust was recorded at a 28° pitch during both simulation and physical testing.
- Experimental results consistently showed 10–15% higher thrust than simulations, likely

due to real airflow dynamics not captured in software.

- The slight underreporting of RPM from the laser tachometer may explain why thrust

appeared higher than predicted at 3000 RPM.

This project successfully demonstrated the feasibility of a variable pitch propeller system through

a blend of simulation and experimental testing. The observed trend showed increasing thrust

with greater pitch angles up to 28°, aligning closely with CFD predictions. Slight deviations

between simulated and experimental values—where physical tests yielded higher thrust—were

attributed to real-world factors such as surface imperfections, minor sensor inaccuracies, and

airflow conditions not captured in simulation.

The manually adjustable pitch mechanism offered a practical and low-cost way to test perfor-

Pitch Angle (°) | Avg Simulated Thrust (N) | Avg Experimental Thrust (N)
0 | 0.12 | 0.16
2 | 0.26 | 0.29
4 | 0.39 | 0.41

mance across configurations. However, it limited dynamic adaptability. Future integration of

servo-actuated pitch control would enable real-time optimization and better emulate in-flight

conditions.

While the indoor test setup provided reliable baseline data, environmental factors like airflow

recirculation and RPM variability introduced potential sources of error. Improved testing in-

frastructure and refined measurement tools would further enhance result accuracy.

Overall, the project lays a strong foundation for advancing toward dynamic pitch systems suit-

able for UAVs and other high-efficiency propulsion applications.

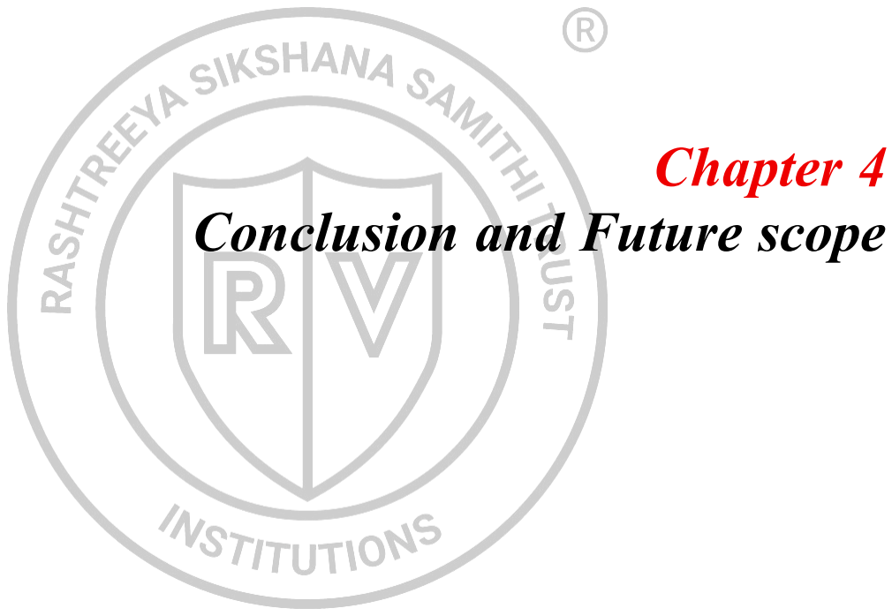
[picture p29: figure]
Conclusion and Future scope

# Chapter 4

This project successfully demonstrated the design, simulation, fabrication, and experimental

validation of a variable pitch propeller system aimed at optimizing thrust output across a range

of pitch angles. Through a systematic methodology combining CAD modeling, computational

fluid dynamics (CFD), physical prototyping, and real-time testing, the intended objectives were

achieved with meaningful engineering insights.

### 4.1 Summary of Work Done

- A complete 3D CAD model of the propeller blade and hub assembly was created in

SolidWorks, with variable pitch configurations ranging from 0° to 30° in 2° increments.

- CFD simulations were conducted using SolidWorks Flow Simulation to evaluate aerody-

namic performance and thrust generation at each pitch angle.

- A modular physical prototype was 3D printed using PLA, allowing easy blade replace-

ment and manual pitch adjustments.

- An experimental test rig was developed using a BLDC motor, ESC, load cell, and tachome- ter

to measure actual thrust at 3000 RPM.

- The system delivered a maximum simulated thrust of 2.20N at 28° pitch, while the ex-

perimental test achieved up to 3.00N, indicating strong correlation and validation of sim-

ulation data.

### 4.2 Key Observations

- Thrust output increased linearly with pitch up to approximately 28°, beyond which slight

reduction or saturation occurred due to probable stall behavior.

- The experimental results outperformed simulations by around 10–15%, primarily due to

unmodeled aerodynamic factors and potential underreporting of actual RPM by the

tachometer.

- The manually adjustable pitch mechanism proved effective in creating a modular and

testable design, suitable for further automation or dynamic pitch control studies.

### 4.3 Limitations

- The static pitch adjustment limited the ability to observe real-time dynamic pitch effects

(such as in-flight transitions).

- Indoor testing conditions may have influenced airflow characteristics, especially recircu-

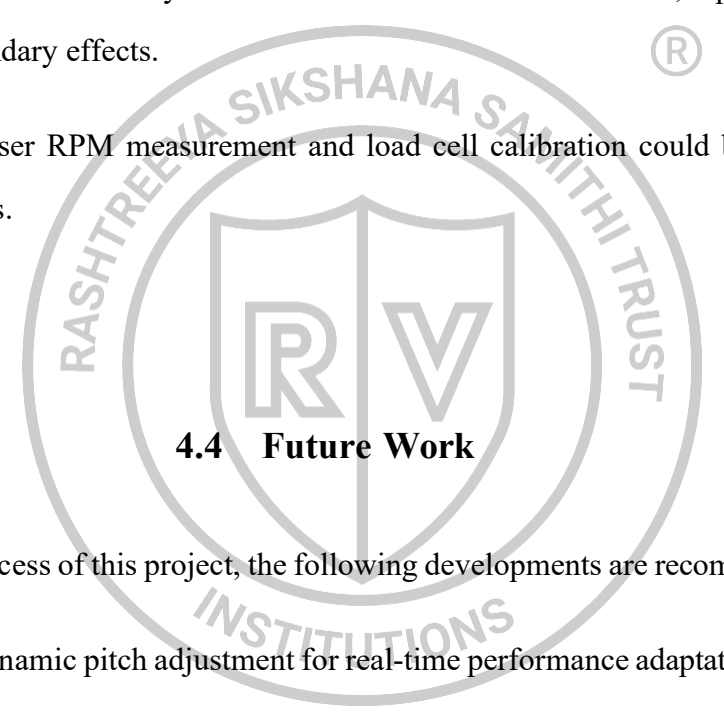
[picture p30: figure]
4.4 Future Work

lation and boundary effects.

- Accuracy of laser RPM measurement and load cell calibration could be improved in

future iterations.

To build upon the success of this project, the following developments are recommended:

- Servo-based dynamic pitch adjustment for real-time performance adaptation.
- Integration of a PID control loop to automatically regulate RPM and pitch based on thrust

demands.

- Testing in an open-jet wind tunnel or outdoor environment to eliminate recirculation and

improve aerodynamic accuracy.

- Fabrication using carbon-fiber or composite materials for higher strength-to-weight ratio

and enhanced performance.

- Incorporation of blade twist and airfoil profiling for further optimization.

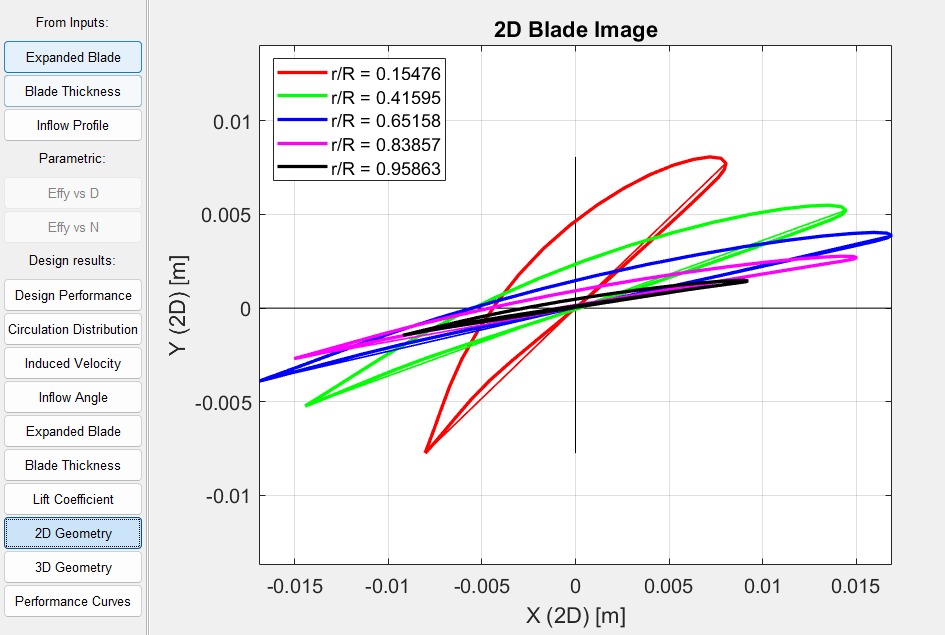
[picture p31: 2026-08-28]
media/images/blade_angel_profile.jpg

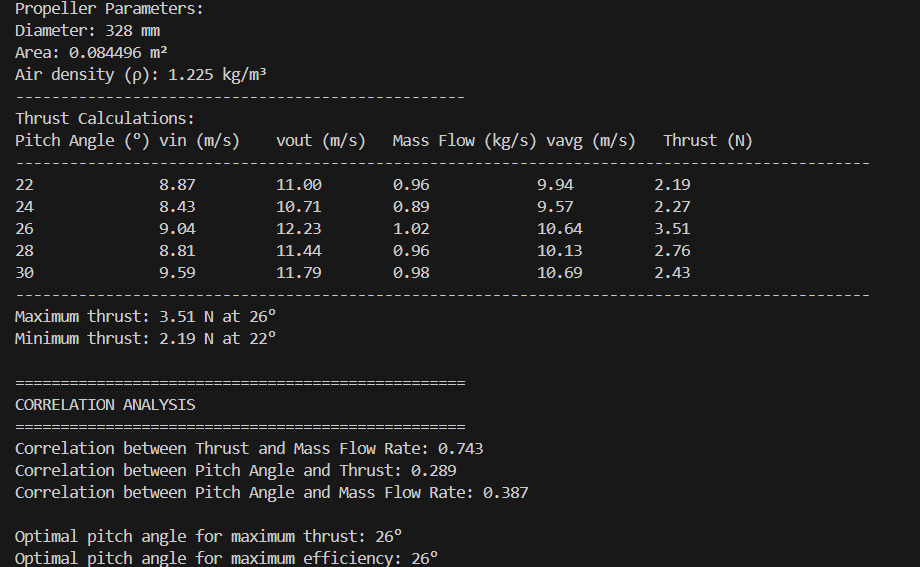
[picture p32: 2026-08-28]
media/images/python_output.png

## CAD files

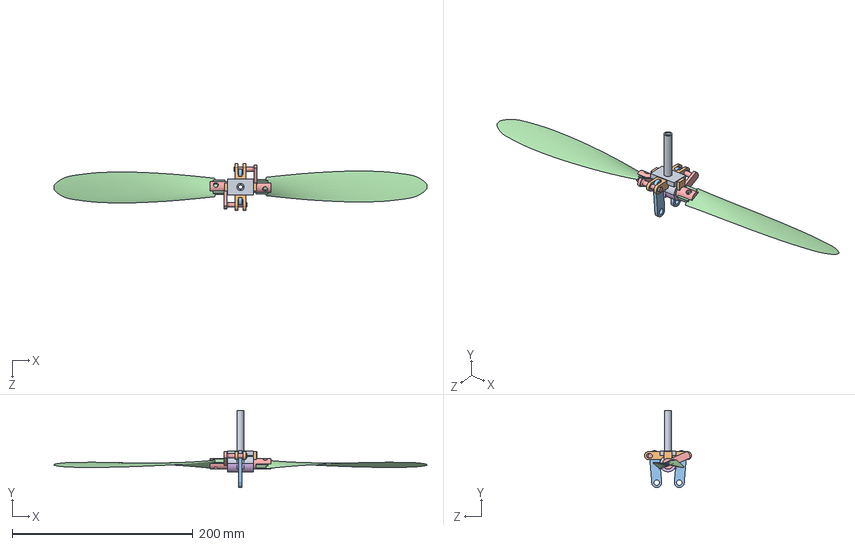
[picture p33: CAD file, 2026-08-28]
cad/whole.SLDASM
412.7 x 85.5 x 51.9 mm
hub
coupler x 2
WING x 2
string x 2
CONT
hub1

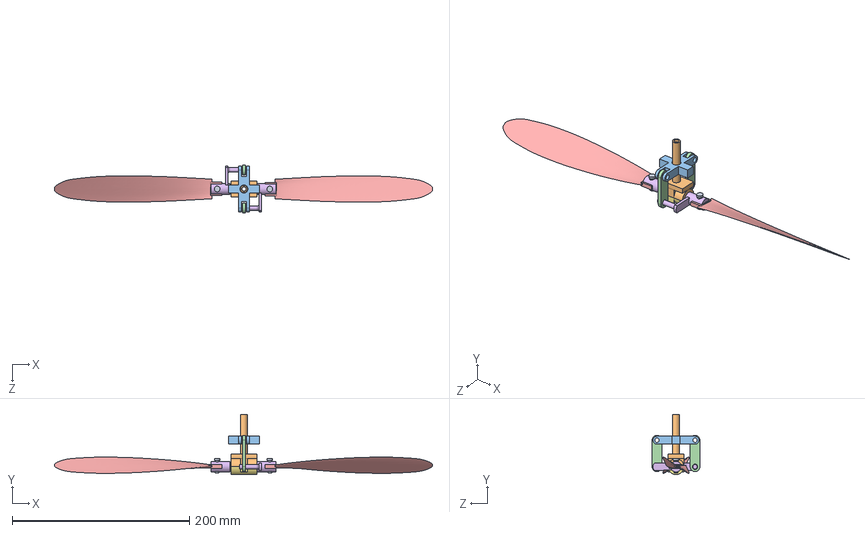
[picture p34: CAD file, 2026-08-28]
cad/Assem1.SLDASM
426.9 x 68.0 x 54.0 mm
hub
coupler x 2
WING x 2
string x 2
CONT
hub1
bolt2 x 2

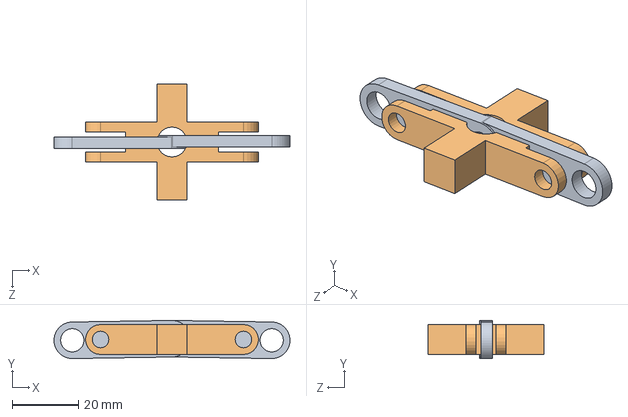
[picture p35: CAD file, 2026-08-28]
cad/print1.SLDASM
71.0 x 11.5 x 35.0 mm
CONT
string x 2

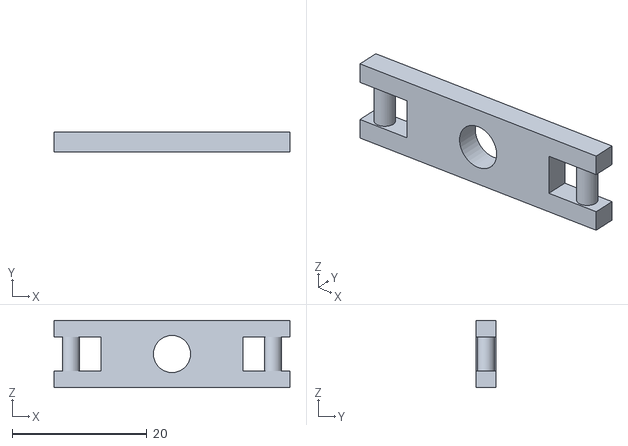
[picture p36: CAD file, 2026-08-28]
cad/print1 - CONT-1.STL
35.0 x 3.00 x 10.0

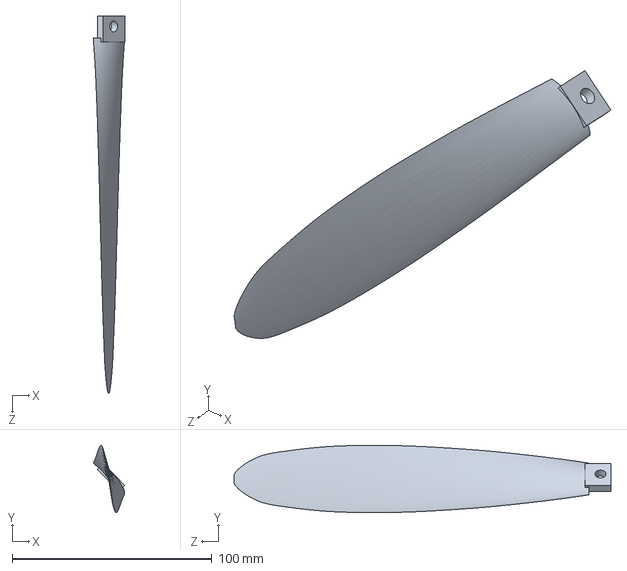
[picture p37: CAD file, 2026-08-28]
cad/WING.SLDPRT
15.8 x 33.7 x 188.9 mm

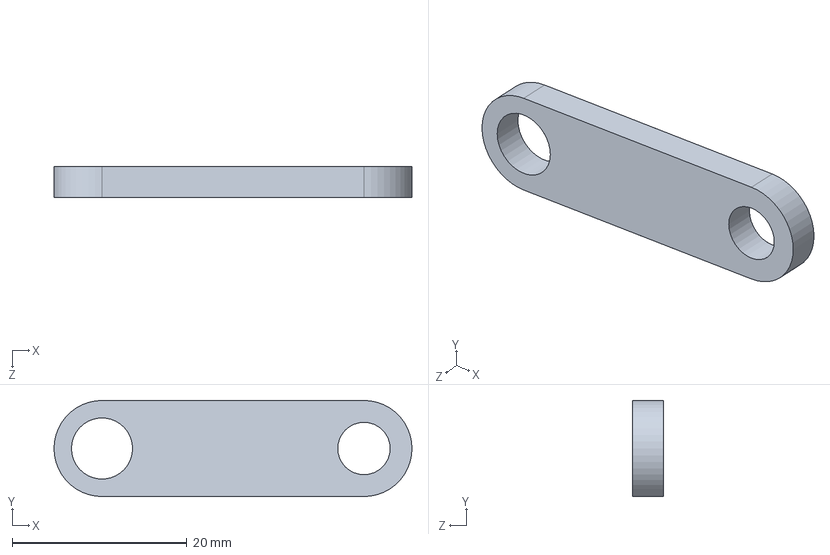
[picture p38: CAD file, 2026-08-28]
cad/string.SLDPRT
41.0 x 11.0 x 3.50 mm

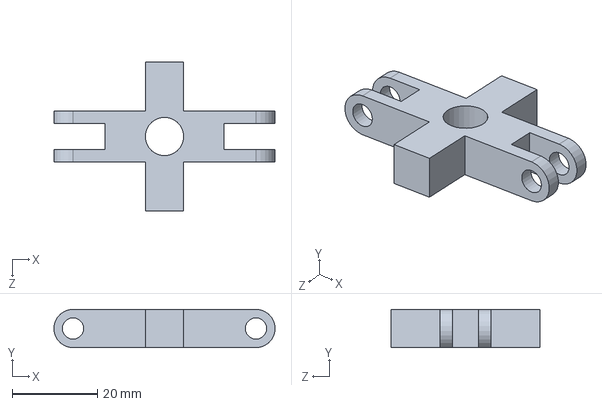
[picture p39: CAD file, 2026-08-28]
cad/CONT.SLDPRT
51.9 x 9.00 x 35.0 mm

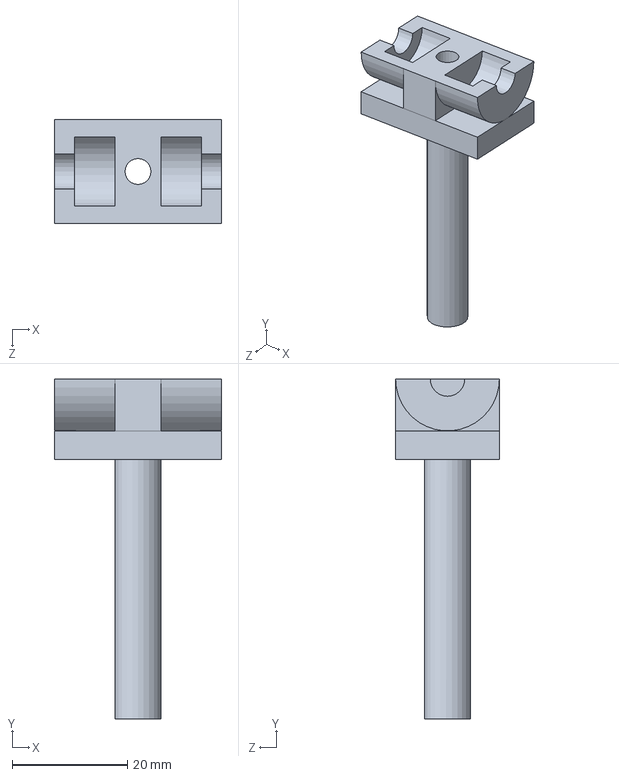
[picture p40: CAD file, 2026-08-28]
cad/hub1.SLDPRT
29.0 x 59.0 x 18.0 mm

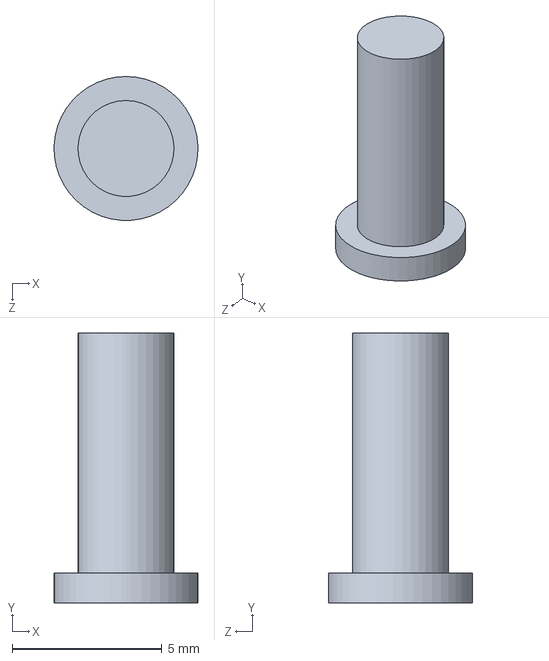
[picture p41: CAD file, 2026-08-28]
cad/Part2.SLDPRT
4.80 x 9.00 x 4.80 mm

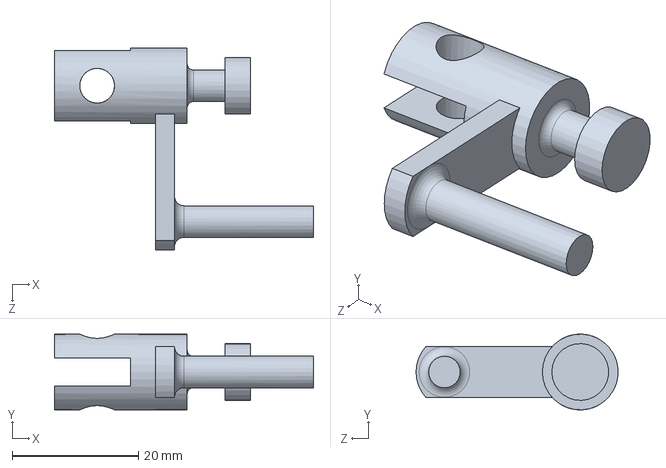
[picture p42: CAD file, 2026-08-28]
cad/coupler.SLDPRT
41.0 x 12.0 x 32.0 mm

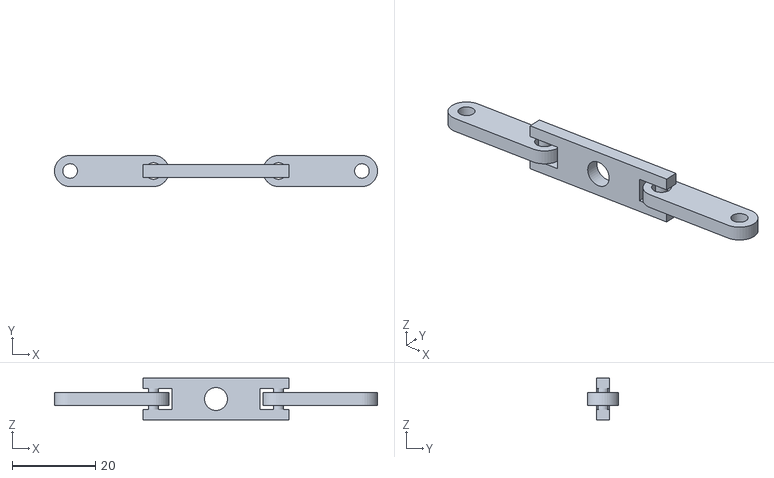
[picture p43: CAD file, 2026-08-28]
cad/p1.STL
77.5 x 7.50 x 10.0

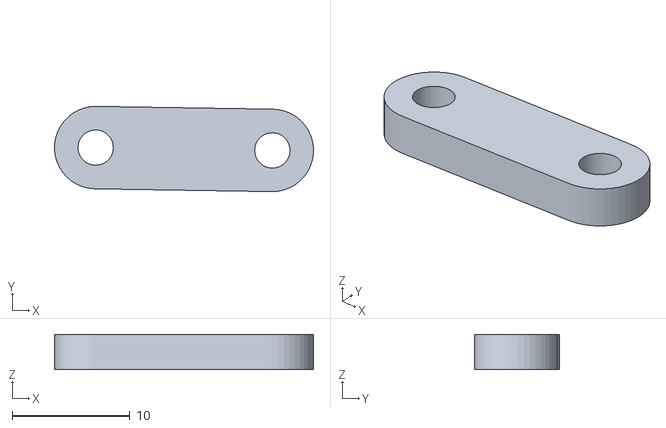
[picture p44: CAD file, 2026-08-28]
cad/print1 - string-2.STL
22.0 x 7.24 x 3.00

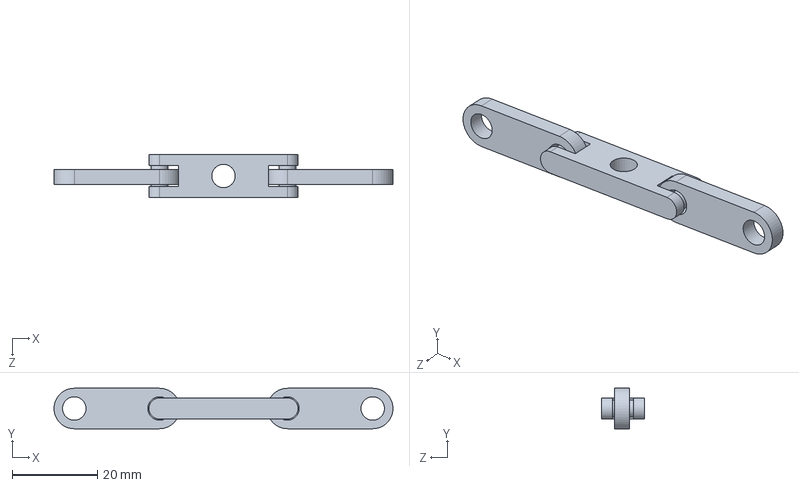
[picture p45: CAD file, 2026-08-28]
cad/printable.SLDPRT
79.5 x 9.50 x 10.0 mm

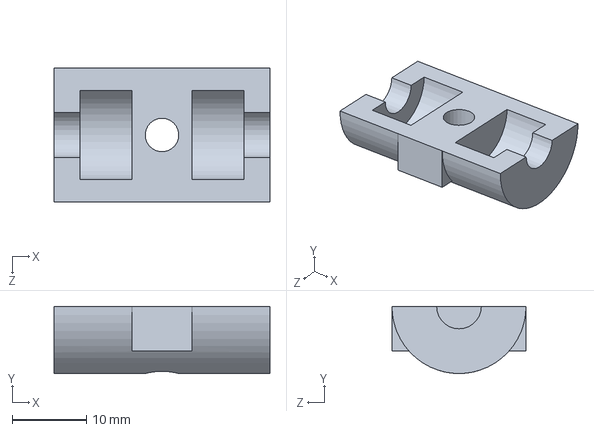
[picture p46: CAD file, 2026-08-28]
cad/hub.SLDPRT
29.0 x 9.00 x 18.0 mm

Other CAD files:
cad/p3.STL
cad/print1 - string-1.STL
cad/p2.STL
cad/bolt2.SLDPRT
cad/bolt1.SLDPRT
cad/bolts.STL

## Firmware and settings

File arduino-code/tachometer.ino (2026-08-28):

const int receiverPin = 2;

// Define the exact number of blades on your propeller.
// This value is CRITICAL for accurate RPM calculation.
const int numberOfBlades = 2; // Example: Set this to the actual number of blades (e.g., 2, 3, 4)

// Variables for RPM calculation (declared as volatile for safe access from ISR)
volatile unsigned long lastInterruptionTime_micros = 0; // Stores the timestamp of the last blade detection
volatile unsigned long rotationPeriod_micros_sum = 0;   // Accumulator for multiple interruption intervals
volatile unsigned int interruptions_count = 0;          // Counts interruptions within a measurement cycle

// Define a smoothing factor for RPM calculation.
// This determines how many interruption intervals are averaged to calculate RPM.
// A higher value provides more stable readings but responds slower to RPM changes.
// A value equal to numberOfBlades means we average over one full rotation.
const int smoothingFactor = numberOfBlades * 1; // Average over two full rotations for stability


long rpm_sum = 0;
long rpm_reading[100];
long rpm_average = 0;
byte n_max = 0;
byte n = 0;


// Flag to control when RPM is updated (prevents frequent updates for stability)
unsigned long lastRPMUpdateTime_millis = 0;
const unsigned long rpmUpdateInterval_millis = 200; // Update RPM every 200 milliseconds

// Function called by the interrupt service routine (ISR)
// This function must be short and fast, avoiding delay(), Serial.print(), etc.
void detectBlade() { // IRAM_ATTR might be useful for some boards, not strictly necessary for Uno
  unsigned long currentInterruptionTime_micros = micros();

  // Only proceed if this is not the very first interruption or if time has passed
  if (lastInterruptionTime_micros != 0) {
    unsigned long interval = currentInterruptionTime_micros - lastInterruptionTime_micros;

    // Filter out very short or very long intervals (noise or extreme speed changes)
    // Adjust these thresholds based on expected RPM range.
    // Assuming min RPM ~60 (1s/rev) and max RPM ~12000 (0.005s/rev).
    // Min interval for 12000 RPM (3 blades) = (60,000,000us / 12000rpm) / 3 blades = 1666 us
    // Max interval for 60 RPM (3 blades) = (60,000,000us / 60rpm) / 3 blades = 333333 us
    if (interval > 500 && interval < 500000) { // Example thresholds: >0.5ms and <0.5s
      rotationPeriod_micros_sum += interval;
      interruptions_count++;
    }
  }
  lastInterruptionTime_micros = currentInterruptionTime_micros;
}

void setup() {
  // Initialize Serial communication for debugging and displaying output
  Serial.begin(2000000);
  Serial.println("-------------------------------------");
  Serial.println("Arduino Propeller RPM Detector");
  Serial.print("Number of Blades: ");
  Serial.println(numberOfBlades);
  Serial.println("Waiting for propeller rotations...");
  Serial.println("-------------------------------------");

  // Configure the receiver pin as an input.
  // INPUT_PULLUP can be used if your sensor module needs an internal pull-up resistor.
  pinMode(receiverPin, INPUT);

  // Attach an interrupt to the receiver pin.
  // digitalPinToInterrupt() maps the digital pin number to the interrupt number.
  // FALLING: The interrupt will trigger when the signal on receiverPin goes from HIGH to LOW.
  //          Choose FALLING, RISING, or CHANGE based on your sensor's behavior.
  attachInterrupt(digitalPinToInterrupt(receiverPin), detectBlade, FALLING);
}

void loop() {
  // Only calculate and print RPM at regular intervals for stable output
  unsigned long currentMillis = millis();
  if (currentMillis - lastRPMUpdateTime_millis >= rpmUpdateInterval_millis) {
    lastRPMUpdateTime_millis = currentMillis;

    // Check if we have collected enough interruption data for a reliable calculation
    if (interruptions_count >= smoothingFactor && rotationPeriod_micros_sum > 0) {
      // Disable interrupts temporarily while accessing volatile variables
      noInterrupts();

      // Calculate the average time between consecutive blade interruptions
      float averageInterruptionInterval_micros = (float)rotationPeriod_micros_sum / interruptions_count;

      // Calculate the time for one full rotation in microseconds
      // Time_per_rotation = Average_Interruption_Interval * Number_of_Blades
      unsigned long timePerRotation_micros = (unsigned long)(averageInterruptionInterval_micros * smoothingFactor);

      // Reset the accumulated sum and count for the next measurement cycle
      rotationPeriod_micros_sum = 0;
      interruptions_count = 0;

      // Re-enable interrupts
      interrupts();

      // Avoid division by zero
      if (timePerRotation_micros > 0) {
       rpm_reading[n] = (60000000 / timePerRotation_micros);
       n_max = constrain(map(rpm_reading[n], 60, 100000, 0, 100), 0, 100);
       n++;
       
       if(n > n_max){
       
         for (byte i = 0; i <= n_max; i++) {
           
           rpm_sum = rpm_sum + rpm_reading[i];
     
         };
         
         rpm_average = rpm_sum / (n_max + 1);     
         rpm_sum = 0;
         n = 0;
        Serial.print("Estimated RPM: ");
        Serial.println(rpm_average);
        delay(1500);
       }
      
    } else {
      // If not enough data collected yet, prompt the user
      // Only print this if we haven't received enough interruptions for calculation
      if (interruptions_count == 0) {
         Serial.println("No propeller detected or insufficient interruptions. Spinning?");
      } else {
         Serial.print("Collecting data... ");
         Serial.print(interruptions_count);
         Serial.print("/");
         Serial.print(smoothingFactor);
         Serial.println(" interruptions received.");
      }
    }
  }
}
}

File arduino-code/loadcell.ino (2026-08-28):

#include <LiquidCrystal_I2C.h>// include the library code
#include <HX711_ADC.h>
#if defined(ESP8266)|| defined(ESP32) || defined(AVR)
#include <EEPROM.h>
#endif
LiquidCrystal_I2C lcd(0x27,16,2);  // set the LCD address and the number of columns and rows
 
//pins:
const int HX711_dout = 4; //mcu > HX711 dout pin
const int HX711_sck = 5; //mcu > HX711 sck pin
 
//HX711 constructor:
HX711_ADC LoadCell(HX711_dout, HX711_sck);
 
const int calVal_eepromAdress = 0;
unsigned long t = 0;
 
void setup() {
    // set up the LCD's number of columns and rows:  
  Serial.begin(9600); delay(10);
  Serial.println();
  Serial.println("Starting...");
 
  LoadCell.begin();
  //LoadCell.setReverseOutput(); //uncomment to turn a negative output value to positive
  float calibrationValue; // calibration value (see example file "Calibration.ino")
  calibrationValue = 409.68; // uncomment this if you want to set the calibration value in the sketch
#if defined(ESP8266)|| defined(ESP32)
  EEPROM.begin(512); // uncomment this if you use ESP8266/ESP32 and want to fetch the calibration value from eeprom
#endif
  EEPROM.get(calVal_eepromAdress, calibrationValue); // uncomment this if you want to fetch the calibration value from eeprom
 
  unsigned long stabilizingtime = 2000; // preciscion right after power-up can be improved by adding a few seconds of stabilizing time
  boolean _tare = true; //set this to false if you don't want tare to be performed in the next step
  LoadCell.start(stabilizingtime, _tare);
  if (LoadCell.getTareTimeoutFlag()) {
    Serial.println("Timeout, check MCU>HX711 wiring and pin designations");
    while (1);
  }
  else {
    LoadCell.setCalFactor(calibrationValue); // set calibration value (float)
    Serial.println("Startup is complete");
  }
}
 
void loop() {
  static boolean newDataReady = 0;
  const int serialPrintInterval = 0; //increase value to slow down serial print activity
  
  // check for new data/start next conversion:
  if (LoadCell.update()) newDataReady = true;
    float i = LoadCell.getData();
    Serial.println("Weight(g): " + String(int(i)));
    delay(15);
  
}
